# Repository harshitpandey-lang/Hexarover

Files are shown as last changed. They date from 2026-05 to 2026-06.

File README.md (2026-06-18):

---
[hexarover zine.pdf](https://github.com/user-attachments/files/28886290/hexarover.zine.pdf)

# HexaRover

> This is an intelligent six wheeled rover inspired from the mars exploration rover and it will be same in design and will be lego based and the main feature of the design is going to be the ease of recreatibility of the complete project. The electronics are replacable while the cadd designes of the legos will be available here with dimesions and links. The desines of the legos can also be used to creat any other project in future also.

---

## Overview

HexaRover is a modular robotics platform built to explore and operate in environments that are difficult, hazardous, or inaccessible to humans. The project integrates embedded electronics, computer vision, wireless communication, and mechanical design into a single scalable rover architecture.

Designed with reliability and adaptability in mind, HexaRover serves as a foundation for experimentation in autonomous systems, remote operations, and intelligent robotics. This is a kind of gateway to enter into lego based bot creation by anybody and embedded systems.

---
## Inspiration 

I was truly amazed and inpsired from the mars rover made by nasa for the mars exploration and its replica by nasa-jpl which github is given here https://github.com/nasa-jpl/open-source-rover. The rovers were very beutiful yet cool and the things which got me in was the structure of them can be made through smaller parts. 
### Probelem being solved
the probelm in these rovers are that they cant be created with the materials which are present in our room solely we need to buy a lot of minutes and minute hardware products and mechanical parts.
So, I decided to make something that can be cretaed using jsut a 3d printer and pvc pipes.

some images of the nasa-jpl rover is given here 




## Mission

To develop a six wheel functional rover which is very cool both in desines and in working. The electronics can be replaced by anybody while the main designes and mechanical parts can be 3d printed by anyone. The recretion of the rover is very easy and the 3d parts can also be used to creat other project in future as well.

---

## Key Features

* Six-Wheel Drive Mobility System
* Modular Electronics Architecture
* ESP32-Based Embedded Control
* Raspberry Pi Vision Processing
* Live Camera Streaming
* Wireless Communication
* Expandable Sensor Support
* Terrain-Oriented Chassis Design
* Remote Monitoring and Operation
* Future Autonomous Navigation Capability

---

## Project Structure

```text
HexaRover/
│
├── README.md
├── LICENSE
├── .gitignore
├── AUTHOR.md
│
├── docs/
├── hardware/
├── software/
└── media/
```

---

## Future Goals

* Autonomous Navigation
* Terrain Mapping
* Object Detection
* Sensor Fusion
* AI-Assisted Decision Making
* Multi-Rover Collaboration

## The Design

The Wirring diagram is given here in kicadd and the kicadd file is also attached in this repo, since the design doesnt require any kind of pb so no pcb was designed for this project while the wirring of the componenets is gievn here 
{85047B80-3A90-4A06-985E-AE78F9C303FE}
Untitled - June 03, 2026 at 04 48 04

---

## Contributing

Contributions are welcome.

If you would like to improve the project:

1. Fork the repository.
2. Create a feature branch.
3. Make your changes.
4. Test thoroughly.
5. Submit a pull request with a clear description of the changes.

Please ensure that all contributions align with the project's objectives and maintain code quality standards.

---

### Access The Parts From Here-

CAD
Wirrings
BOM
Jornel
Steps To Recreate

## License

This project is licensed under the MIT License.

See the LICENSE file for complete details.

---

<div align="center">

### HexaRover

*Exploring the Unknown.*

</div>

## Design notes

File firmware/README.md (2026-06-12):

# Firmware Structure

This directory contains the complete ESP32 firmware for HexaRover.

## Build & Upload

Using PlatformIO:
```bash
cd firmware
pio run -e esp32doit-devkit-v1
pio run -e esp32doit-devkit-v1 --target upload
```

Or Arduino IDE:
- Open `src/main.cpp`
- Select board: ESP32 DevKit V1
- Select port and upload

## File Organization

```
firmware/
├── platformio.ini          # Build configuration
├── src/
│   ├── main.cpp            # Main firmware entry point
│   ├── motor_controller.h/cpp   # BTS7960 motor driver interface
│   ├── servo_controller.h/cpp   # MG946R servo interface  
│   ├── sensor_manager.h/cpp     # IMU, GPS, ultrasonic handling
│   ├── receiver.h/cpp          # FlySky FS-iA6B iBUS receiver
│   ├── telemetry.h/cpp         # Telemetry to Raspberry Pi
│   └── main.py             # Raspberry Pi control app
├── setup.py                # RPi dependency installer
└── WIRING.md              # Hardware connection guide
```

## Module Overview

### Motor Controller
Manages dual BTS7960 motor drivers with PWM speed control. Supports independent left/right control and synchronized forward/reverse motion.

### Servo Controller  
Controls four MG946R steering servos via PWM. All servos synchronized for unified steering angle.

### Sensor Manager
Aggregates data from:
- MPU6050 IMU (roll, pitch, yaw via I2C)
- NEO-6M GPS (coordinates, satellite count via UART1)
- HC-SR04 ultrasonic sensors (front & rear distance via GPIO)

### Receiver Manager
Decodes FlySky FS-iA6B iBUS protocol at 115200 baud. Extracts 14 channels with failsafe detection on signal loss.

### Telemetry Manager
Sends formatted telemetry packets to Raspberry Pi at 10 Hz containing mode, distances, GPS, and orientation data.

## Key Features

- **Modular Class Architecture**: Each subsystem is independent and reusable
- **Failsafe Logic**: Automatic stop & center steering on receiver signal loss
- **Autonomous Mode**: Obstacle avoidance with front distance sensor
- **Live Telemetry**: Continuous sensor streaming to Raspberry Pi
- **Debug Output**: Serial console logging for development

## Compilation Requirements

- PlatformIO IDE or Arduino IDE
- ESP32 Board Support Package
- Libraries:
  - ESP32Servo
  - MPU6050
  - TinyGPS++
  - Adafruit-BusIO

All handled automatically by platformio.ini

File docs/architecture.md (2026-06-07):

# HexaRover Architecture

## Overview

HexaRover is a modular ESP32-powered robotic rover platform designed for education, experimentation, and open-source robotics development. The system combines custom 3D-printed structural components, wireless communication, embedded control systems, and modular hardware interfaces to create a platform that can be easily assembled, modified, and extended.

The architecture emphasizes:

* Modularity
* Reproducibility
* Scalability
* Low-cost manufacturing
* Open-source development
* Educational accessibility

---

# System Architecture

```text
                    ┌─────────────────────┐
                    │   User Controller   │
                    │ (Phone / Web App)   │
                    └──────────┬──────────┘
                               │
                        Wi-Fi / Bluetooth
                               │
                               ▼
                    ┌─────────────────────┐
                    │       ESP32         │
                    │ Main Control Unit   │
                    └───────┬─────┬───────┘
                            │     │
            ┌───────────────┘     └───────────────┐
            ▼                                     ▼

   ┌─────────────────┐                  ┌─────────────────┐
   │ Motor Driver    │                  │ Sensor Network  │
   │ (L298N/TB6612)  │                  │ Expansion Bus   │
   └────────┬────────┘                  └────────┬────────┘
            │                                    │
            ▼                                    ▼

   ┌─────────────────┐                ┌──────────────────┐
   │ Drive Motors    │                │ Future Sensors   │
   │ Wheel System    │                │ IMU, Ultrasonic  │
   └─────────────────┘                │ GPS, Camera etc. │
                                      └──────────────────┘
```

---

# Hardware Architecture

## Chassis Layer

The chassis serves as the structural foundation of HexaRover.

### Responsibilities

* Support electronic components
* Mount motors and wheels
* Protect internal systems
* Enable modular expansion

### Construction

The chassis consists of:

* Sunboard prototype structure
* Custom 3D-printed components
* LEGO-inspired modular connectors
* Reinforcement supports
* Electronics mounting points

### Design Principles

* Lightweight construction
* Easy assembly
* Replaceable components
* Standardized connection interfaces

---

## Mechanical Subsystem

The mechanical subsystem converts electrical energy into rover movement.

### Components

| Component | Function |
| --- | --- |
| Drive Wheels | Ground mobility |
| Motor Mounts | Secure motor positioning |
| Connector System | Structural assembly |
| Reinforcement Elements | Load distribution |
| Chassis Frame | System support |

### Features

* Modular wheel assemblies
* Serviceable components
* Expandable frame design
* Future payload support

---

## Electronics Architecture

The electronics subsystem acts as the control and communication backbone of the rover.

### Core Controller

**ESP32 Development Board**

Responsibilities:

* Wireless communication
* Sensor data processing
* Motor control
* Firmware execution
* Future AI integrations

### Why ESP32

* Dual-core processor
* Wi-Fi support
* Bluetooth support
* Multiple GPIO interfaces
* Large community support
* Cost effectiveness

---

## Power Distribution Layer

The power system distributes energy to all rover subsystems.

### Responsibilities

* Stable voltage delivery
* Current protection
* Battery integration
* Component isolation

### Planned Power Flow

```text
Battery Pack
      │
      ▼
Power Regulation
      │
 ┌────┴────┐
 ▼         ▼

ESP32   Motor Driver
            │
            ▼
         Motors
```

### Future Improvements

* Battery monitoring
* Overcurrent protection
* Charging subsystem
* Power telemetry

---

## Motor Control Architecture

The motor control subsystem interfaces between the ESP32 and drive motors.

### Responsibilities

* Speed control
* Direction control
* Differential steering
* PWM signal processing

### Planned Hardware

* L298N Motor Driver (Prototype)
  or
* TB6612FNG (Future Upgrade)

### Control Flow

```text
User Command
      │
      ▼
ESP32 Firmware
      │
      ▼
Motor Driver
      │
      ▼
DC Motors
```

---

# Sensor Architecture

HexaRover is designed with a sensor-first expansion philosophy.

The base platform functions without sensors but includes provisions for future integration.

### Planned Sensor Modules

| Sensor | Purpose |
| --- | --- |
| Ultrasonic | Obstacle detection |
| IMU | Orientation tracking |
| GPS | Navigation |
| Camera | Vision processing |
| Encoders | Motion feedback |
| Environmental Sensors | Data collection |

### Expansion Goals

* Plug-and-play sensor integration
* Standardized interfaces
* Modular firmware support

---

# Communication Architecture

The communication subsystem enables wireless control and monitoring.

## Bluetooth Mode

Designed for:

* Mobile control
* Quick setup
* Offline operation

### Use Cases

* Manual driving
* Classroom demonstrations
* Testing

---

## Wi-Fi Mode

Designed for:

* Long-range operation
* Web dashboard control
* Remote monitoring

### Future Features

* OTA firmware updates
* Telemetry streaming
* Multi-device control

---

# Software Architecture

The software stack follows a layered design.

```text
Application Layer
        │
        ▼
Control Layer
        │
        ▼
Hardware Abstraction Layer
        │
        ▼
ESP32 Hardware
```

---

## Application Layer

Responsible for:

* User commands
* Dashboard interfaces
* Autonomous routines
* Data visualization

---

## Control Layer

Responsible for:

* Motion algorithms
* Steering logic
* Sensor fusion
* Decision making

---

## Hardware Abstraction Layer

Provides a consistent interface between software and hardware.

### Benefits

* Easier maintenance
* Hardware independence
* Improved scalability
* Cleaner code organization

---

# Firmware Architecture

The firmware is divided into independent modules.

```text
Firmware
│
├── Motor Controller
├── Wireless Manager
├── Sensor Manager
├── Power Monitor
├── Configuration Manager
└── Diagnostics Module
```

Each module performs a specific task and communicates through well-defined interfaces.

---

# Repository Architecture

```text
HexaRover/
│
├── CAD/
│   ├── Connectors/
│   ├── Chassis/
│   └── Assembly/
│
├── Hardware/
│   ├── Components/
│   ├── Wiring/
│   └── PCB/
│
├── Firmware/
│   ├── Core/
│   ├── Drivers/
│   ├── Sensors/
│   └── Communication/
│
├── Docs/
│   ├── Architecture.md
│   ├── Journal.md
│   ├── Assembly.md
│   └── Wiring.md
│
├── Images/
│
└── README.md
```

---

# Scalability Roadmap

The architecture has been designed to support future enhancements without requiring a complete redesign.

### Planned Upgrades

* Autonomous navigation
* Computer vision
* AI-assisted driving
* ROS integration
* Custom PCB development
* Swarm robotics experimentation
* Edge AI processing

---

# Design Philosophy

HexaRover is built around five core principles:

### Modularity

Every subsystem should be replaceable without affecting the rest of the platform.

### Accessibility

The rover should be buildable using commonly available tools and components.

### Open Source

All designs, firmware, and documentation should remain openly available.

### Educational Value

The platform should serve as a practical learning tool for robotics and embedded systems.

### Scalability

The architecture should support growth from a simple rover to a sophisticated autonomous robotics platform.

---

# Conclusion

HexaRover is more than a rover project; it is a modular robotics platform designed to bridge mechanical engineering, electronics, embedded systems, and software development. The architecture prioritizes flexibility, maintainability, and reproducibility, ensuring that future contributors can extend the platform while preserving a clean and organized system design.

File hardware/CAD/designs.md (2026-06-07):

WhatsApp Image 2026-06-07 at 10 52 28 AM
the cadd designes are given here one by one WhatsApp Image 2026-06-07 at 10 46 33 AM
WhatsApp Image 2026-06-07 at 10 46 33 AM (1)
WhatsApp Image 2026-06-07 at 10 46 34 AM
WhatsApp Image 2026-06-07 at 10 46 34 AM (1)
WhatsApp Image 2026-06-07 at 10 46 35 AM
WhatsApp Image 2026-06-07 at 10 46 38 AM
WhatsApp Image 2026-06-07 at 10 46 36 AM
WhatsApp Image 2026-06-07 at 10 46 37 AM
WhatsApp Image 2026-06-07 at 10 46 37 AM (1)

WhatsApp Image 2026-06-07 at 10 52 30 AM
WhatsApp Image 2026-06-07 at 10 52 29 AM (1)
WhatsApp Image 2026-06-07 at 10 52 29 AM

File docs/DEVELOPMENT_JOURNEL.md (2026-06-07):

# HexaRover Development Journal

## Project Overview

HexaRover is an open-source modular rover platform designed to be accessible, reproducible, and educational. The project combines custom 3D-printed structural components, ESP32-based control electronics, and a lightweight chassis architecture to create a robotics platform that can be assembled and modified by students, hobbyists, and makers.

The primary objective of the project is to develop a rover that can be reproduced using commonly available materials while providing opportunities to learn CAD design, mechanical engineering, embedded systems, electronics integration, and open-source hardware development.

---

## Concept Development and Chassis Design

The project began with an evaluation of available components and manufacturing constraints. Rather than designing a conventional rover around expensive custom-machined parts, the design philosophy focused on modularity and ease of fabrication.

A lightweight chassis structure was selected as the foundation of the platform. Initial prototypes were constructed using sunboard panels to rapidly validate dimensions, structural layout, and component placement before committing to detailed CAD development.

This prototyping phase established the overall footprint of the rover and provided a practical framework for future mechanical design decisions.

### Key Deliverables

* Initial rover architecture defined.
* Chassis dimensions finalized.
* Structural layout validated through physical prototyping.
* Manufacturing constraints identified before CAD development.

---

## Development of Modular Mechanical Components

A major goal of HexaRover is to enable easy assembly and customization. To achieve this, a modular mechanical ecosystem was developed using LEGO-inspired design principles.

Using Autodesk Fusion, a collection of interlocking structural components was designed to serve as the foundation of the rover's mechanical framework. These parts were dimensioned for 3D printing and intended to allow users to modify or expand the rover without redesigning the entire platform.

The design process focused on creating standardized connection interfaces that could be reused throughout the system.

### Components Developed

* Structural connectors
* Joint mechanisms
* Mounting interfaces
* Support brackets
* Modular attachment elements

### Engineering Considerations

* Printability on consumer-grade 3D printers.
* Dimensional consistency across all modules.
* Structural integrity under expected operating loads.
* Ease of assembly and replacement.

---

## Mechanical System Integration

Following the development of individual components, the project entered the assembly design stage.

The modular parts were integrated into a complete rover architecture within Fusion. Multiple iterations were performed to ensure alignment between structural members, mounting locations, and future electronics integration requirements.

This stage transformed a collection of individual components into a cohesive mechanical system capable of supporting mobility hardware, electronics, and future payloads.

### Accomplishments

* Complete digital assembly created.
* Structural relationships validated.
* Mounting geometry established.
* Mechanical compatibility verified across modules.

### Challenges

As with most modular systems, dimensional tolerances became increasingly important as the number of interconnected parts increased. Several design revisions were performed to improve compatibility and simplify future assembly.

---

## Structural Optimization

To improve durability and load distribution, additional reinforcement elements were introduced into the design.

These components were intended to increase chassis rigidity while maintaining the modular philosophy of the project. Support structures were added to improve the strength of critical mounting locations and reduce stress concentrations throughout the frame.

This phase marked the transition from a proof-of-concept model toward a more robust engineering design.

### Outcomes

* Increased structural stability.
* Improved load distribution.
* Enhanced support for future electronics integration.
* Better long-term durability of the chassis.

---

## Repository Architecture and Documentation

In parallel with hardware development, work began on organizing the project's software and documentation infrastructure.

The repository was structured to support future development, collaboration, and reproducibility. Documentation was treated as a core component of the project rather than an afterthought.

The goal is to ensure that anyone can reproduce the rover using only the repository contents and commonly available tools.

---

## Visualization and Design Validation

Before physical fabrication, high-quality rendered models were generated from the completed CAD assembly.

These renders served multiple purposes:

* Visual verification of the final design.
* Documentation and presentation material.
* Identification of potential design inconsistencies.
* Creation of media assets for project communication.

The rendering process provided an opportunity to review the complete system before moving further into fabrication and electronics integration.

---

## Electronics Planning and System Architecture

With the mechanical design substantially complete, attention shifted toward electronics integration.

The control architecture is centered around the ESP32 platform due to its processing capabilities, wireless connectivity, and suitability for robotics applications.

Before creating formal schematics, the complete wiring architecture was first developed on paper. This approach allowed signal routing, power distribution, and component relationships to be analyzed before implementation in electronic design software.

### Areas of Focus

* ESP32 pin allocation.
* Motor control architecture.
* Power distribution planning.
* Sensor integration pathways.
* Future expansion capabilities.

### Design Philosophy

The electronics system is being developed with the same modular principles as the mechanical structure, allowing future upgrades without requiring significant redesign of the platform.

---

## Current Status

At the present stage of development:

* Mechanical architecture has been designed and validated digitally.
* Modular 3D-printable components have been developed.
* Structural reinforcement elements have been incorporated.
* Repository organization and documentation have been established.
* Visual renders have been generated.
* Electronics planning and wiring architecture are underway.

The project is now transitioning from digital design and planning into fabrication, electronics implementation, firmware development, and system testing.

---

## Future Work

Upcoming development milestones include:

* Fabrication of 3D-printed components.
* Assembly of the physical rover platform.
* Electronics integration.
* PCB and schematic development.
* ESP32 firmware implementation.
* Wireless control functionality.
* Sensor integration and testing.
* Field validation and performance optimization.
* Release of complete open-source documentation.

---

## Conclusion

HexaRover represents an effort to create an accessible and reproducible robotics platform that bridges mechanical design, electronics, embedded systems, and open-source engineering. By emphasizing modularity, documentation, and ease of replication, the project aims to provide a practical learning platform for students, makers, and robotics enthusiasts while serving as a foundation for future experimentation and development.

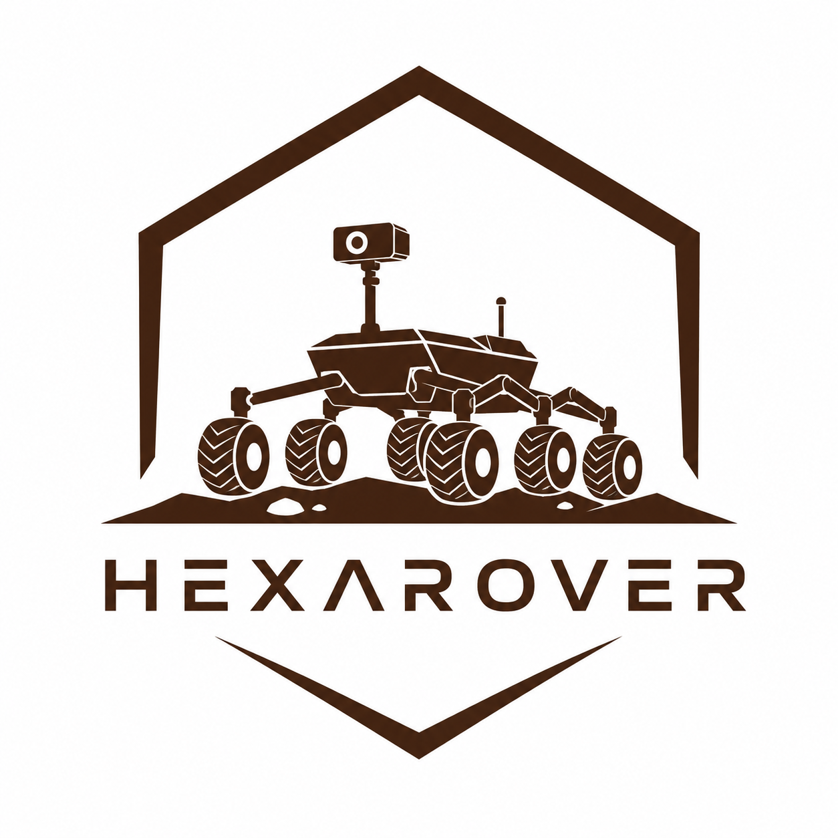
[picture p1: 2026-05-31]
Media/rover_images/ May 30, 2026, 09_19_28 PM.png

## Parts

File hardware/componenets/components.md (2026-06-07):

71ojeUPQI9L
51cDDThzC1L
41vruQ(3)
NEO6MV2-gps-module_9fbf4879-e287-42eb-b1ce-58d4beed52e1
unnamed_64e02225-e6c5-4890-8380-92216c35b1bb

Ultrasonic-Sensor-Module-HC-SR04
MPU6050-Gyroscope-Sensor
LM25962ABuckStep-downPowerConverterModuleDC4-40Vto1 3-37VwithLEDVoltmeter2
GB37-55512VDCGearMotor-300RPM_3_large
GB37-55512VDCGearMotor-300RPM_2_large

DoubleBTS796043AH-BridgeHigh-PowerStepperMotorDriverModule_2
DoubleBTS796043AH-BridgeHigh-PowerStepperMotorDriverModule_1
BTS7960-43a-dual-motor-controller-7-Cropped_480x480
BlueskyMini5V3AUBECforFPVGimbalandRCDroneModels2
616zO4AQmmL _SL1500_
61l1xE23BhL _SL1500_
61b2MmjYhOL _SL1000_

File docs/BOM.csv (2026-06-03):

Category | Supplier | Component | Quantity | Unit Price INR | Subtotal INR | Purchase Link
Drive System | Quartz Components | GB37-555 12V DC Gear Motor 300RPM | 6 | 608 | 3648 | https://quartzcomponents.com/products/gb37-555-12v-dc-gear-motor-300rpm?variant=45639417790698
Drive System | Quartz Components | Double BTS7960 43A H-Bridge Driver | 2 | 273 | 546 | https://quartzcomponents.com/products/double-bts7960-43a-h-bridge-high-power-stepper-motor-driver-module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
Steering System | Robu.in | TowerPro MG946R Digital Metal Gear Servo | 4 | 438 | 1752 | https://robu.in/product/towerpro-mg946r-digital-high-torque-metal-gear-servo-motor/
Wheel System | Sun Electronics | 11cm x 4cm High Load Robotic Wheel | 6 | 140 | 840 | https://sunelectronics.co.in/product/robotic-wheel-for-high-load-11cm-x-4cm-wheel-for-robotfor-engineering-project/
Power System | Quartz Components | WATTNINE 12V 7.2Ah Li-Ion Battery Pack | 1 | 1652 | 1652 | https://quartzcomponents.com/products/12v-7200mah-li-ion-battery-pack-with-1-year-warranty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
Power System | Quartz Components | LM2596 Buck Converter with Voltmeter | 1 | 108 | 108 | https://quartzcomponents.com/products/lm2596-2a-buck-step-down-power-converter-module-dc-4-40v-to-1-3-37v-with-led-voltmeter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
Power System | Quartz Components | XT60 Connector Pair | 2 | 26 | 52 | https://quartzcomponents.com/products/xt60?variant=42158646624490
Navigation | Quartz Components | NEO6MV2 GPS Module | 1 | 235 | 235 | https://quartzcomponents.com/products/neo6mv2-gps-module-with-flight-controller?variant=31898002980999
Sensors | Quartz Components | MPU6050 Gyroscope Accelerometer Module | 1 | 156 | 156 | https://quartzcomponents.com/products/mpu6050-gyroscope-accelerometer-sensor?variant=31897777733767
Sensors | Quartz Components | HC-SR04 Ultrasonic Sensor | 4 | 72 | 288 | https://quartzcomponents.com/products/hc-sr04-ultrasonic-sensor-module?variant=31897769410695
Vision System | Sun Electronics | Raspberry Pi 3 Camera 5MP | 1 | 260 | 260 | https://sunelectronics.co.in/product/raspberry-pi-3-camera-5-mp/
Wiring | Quartz Components | Jumper Wire Combo Pack (120pcs) | 1 | 145 | 145 | https://quartzcomponents.com/products/jumper-wires-combo-pack-male-to-male-male-to-female-female-to-female-set-of-120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
Wiring | Robu.in | Servo Extension Cable 15cm | 4 | 50 | 200 | https://robu.in/product/safeconnect-twisted-15cm-22awg-servo-lead-extension-jr-cable-with-self-locking-hook/
Wiring | Robu.in | PVC Heat Shrink Sleeve 93mm | 1 | 31 | 31 | https://robu.in/product/pvc-heat-shrink-sleeve-93mm-orange/
Control System | User Inventory | Raspberry Pi 4 Model B | 1 | 0 | 0 | Already Owned
Control System | User Inventory | FlySky FS-i6 Transmitter | 1 | 0 | 0 | Already Owned
Control System | User Inventory | FlySky Receiver | 1 | 0 | 0 | Already Owned
Control System | User Inventory | 32GB Class 10 MicroSD Card | 1 | 0 | 0 | Already Owned
Power System | Amazon | 15A ATC Automotive Blade Fuse | 1 | 80 | 80 | https://amzn.in/d/08DSf7vK
Power System | Amazon | DC Power Jack Connector Set (10 Male + 10 Female) | 1 | 299 | 299 | https://amzn.in/d/0b6YXhBp
Power System | Amazon | RC Servo BEC UBEC Voltage Regulator 5V 15A | 1 | 1672 | 1672 | https://amzn.in/d/0f6fojOy
Control System | Quartz Components | ESP32 30 Pin CP2102 Development Board | 1 | 385 | 385 | https://quartzcomponents.com/products/esp32-30-pin-development-board-with-wi-fi-and-bluetooth
TOTAL |  |  |  |  | 12547

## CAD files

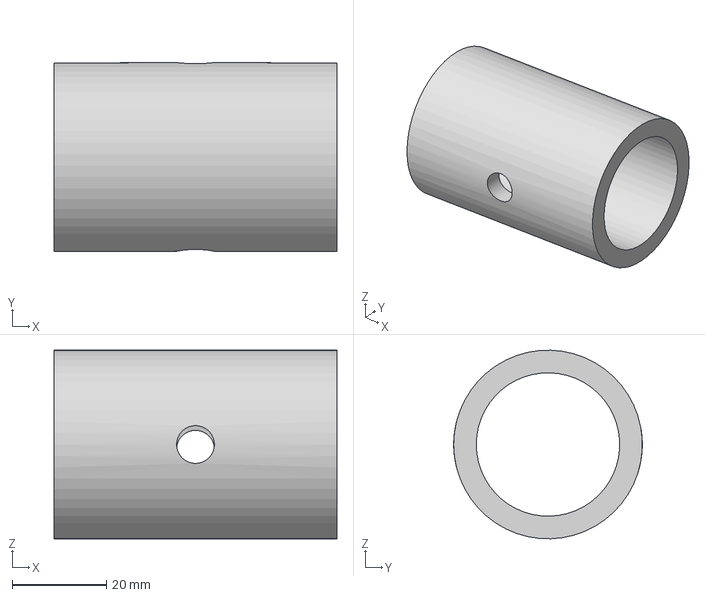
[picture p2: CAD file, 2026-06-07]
hardware/CAD/J8.step
60.0 x 40.0 x 40.0 mm

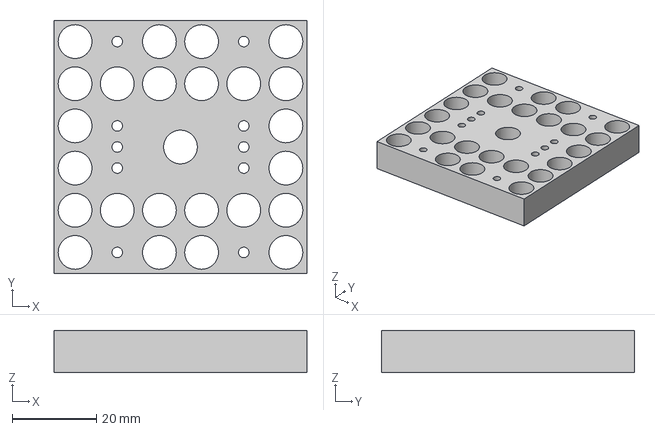
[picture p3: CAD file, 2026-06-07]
hardware/CAD/J3.step
60.0 x 60.0 x 10.0 mm

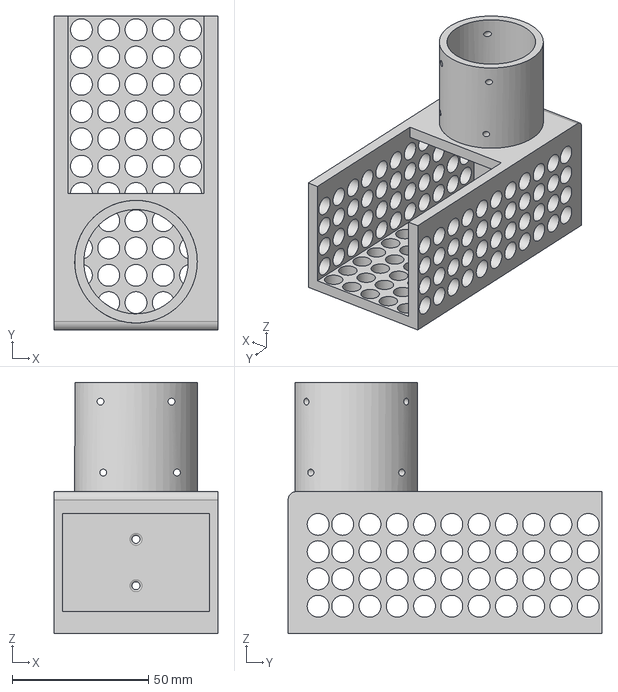
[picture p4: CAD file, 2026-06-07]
hardware/CAD/j12.step
60.0 x 115.0 x 92.0 mm

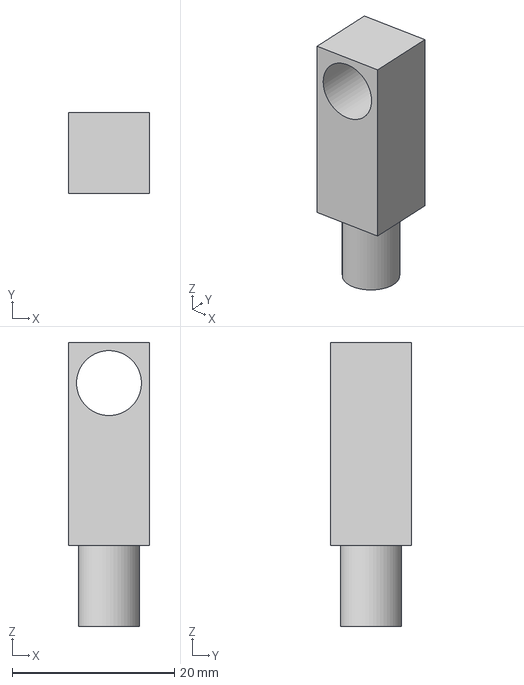
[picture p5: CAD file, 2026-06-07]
hardware/CAD/J4.step
10.0 x 10.0 x 35.0 mm

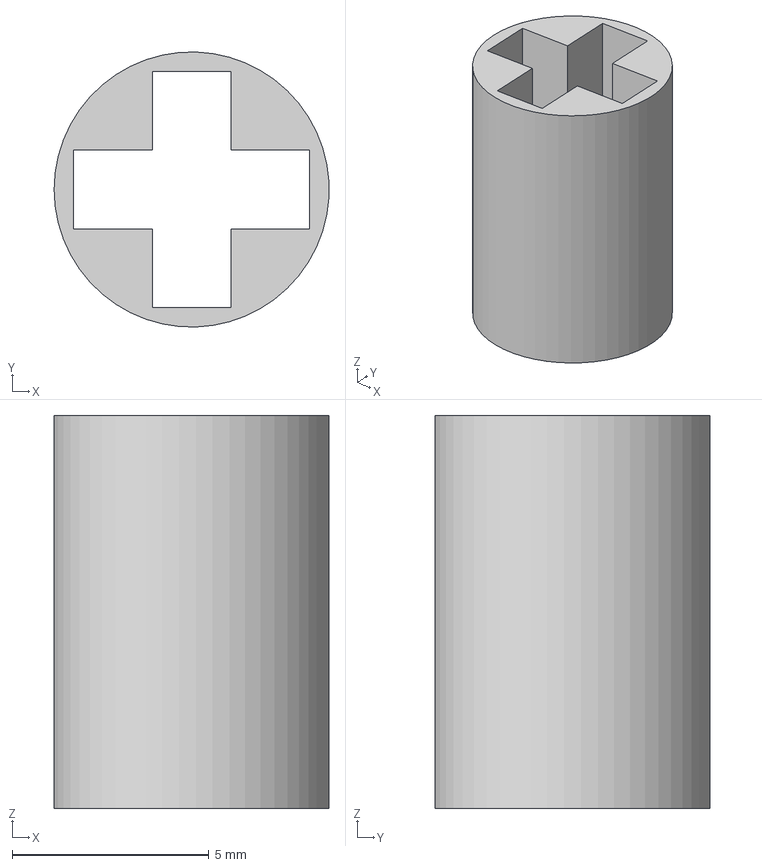
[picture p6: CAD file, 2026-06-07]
hardware/CAD/J2.step
6.99 x 7.00 x 10.0 mm

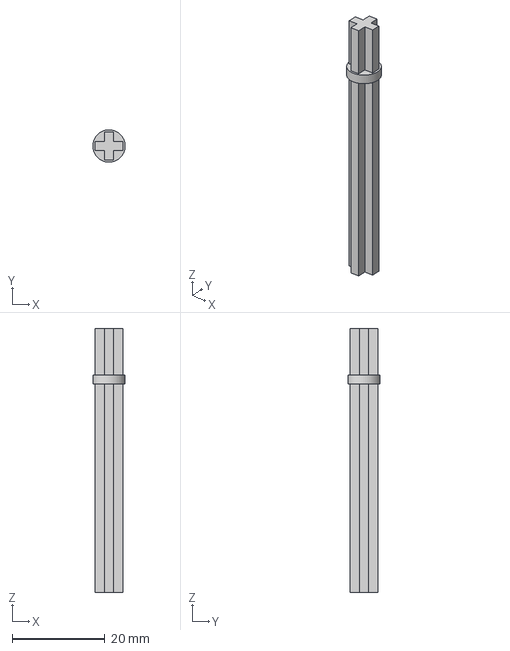
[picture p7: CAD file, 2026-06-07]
hardware/CAD/J1.step
6.99 x 7.00 x 57.0 mm

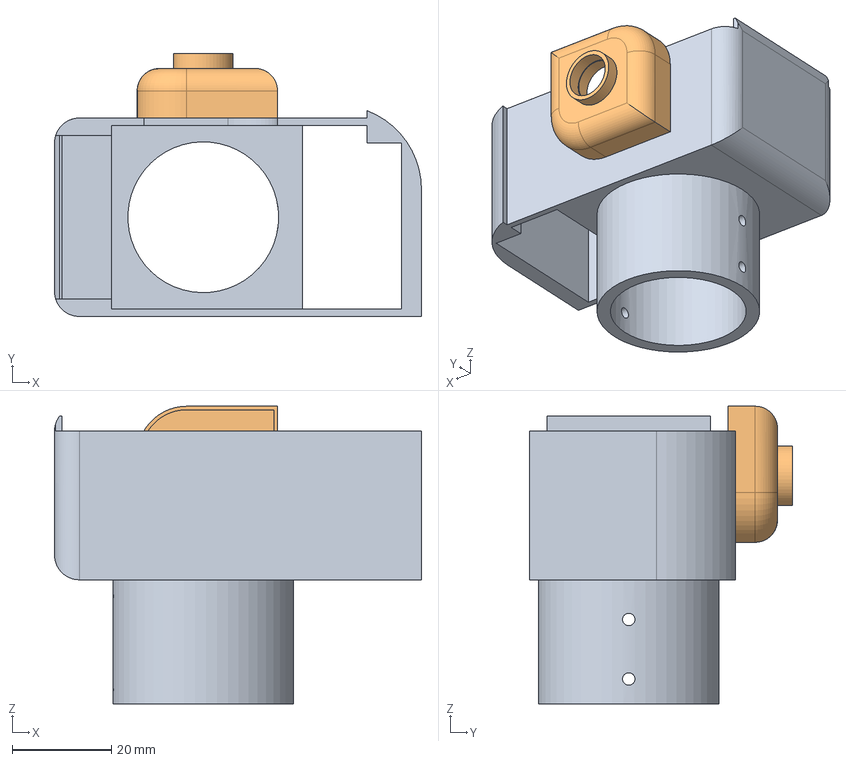
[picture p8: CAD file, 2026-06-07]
hardware/CAD/J13.step
74.0 x 53.0 x 60.0 mm

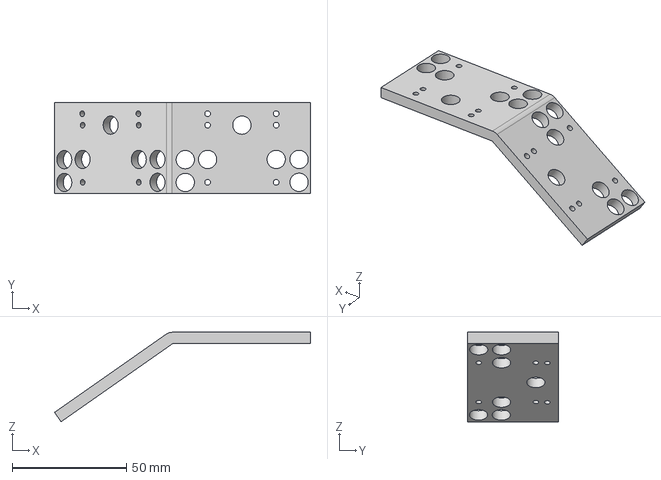
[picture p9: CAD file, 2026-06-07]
hardware/CAD/J6.step
112.0 x 40.0 x 39.1 mm

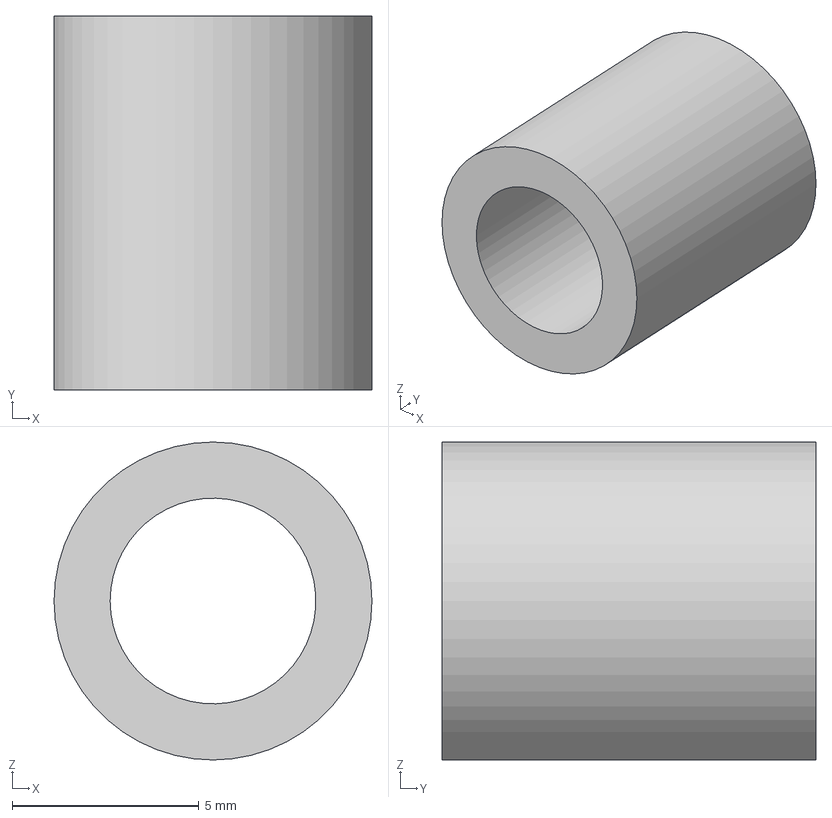
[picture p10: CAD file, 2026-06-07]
hardware/CAD/L3.step
8.50 x 10.0 x 8.50 mm

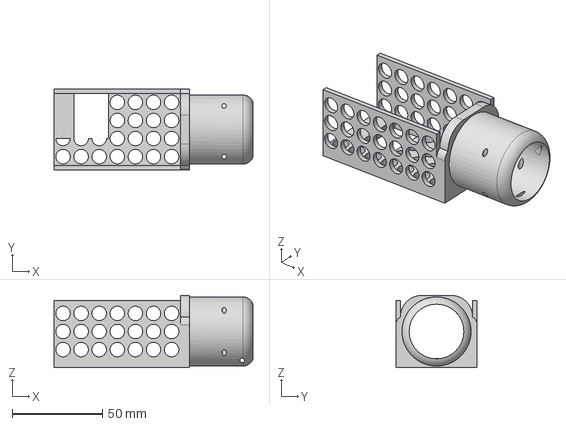
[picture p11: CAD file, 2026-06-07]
hardware/CAD/j11.step
110.0 x 45.0 x 40.0 mm

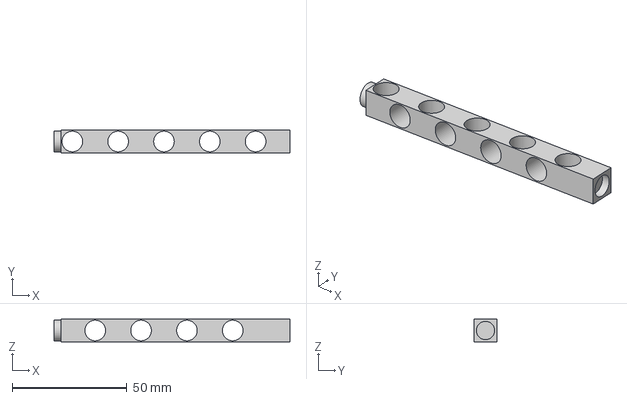
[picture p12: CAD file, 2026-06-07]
hardware/CAD/L2.step
103.0 x 10.0 x 10.0 mm

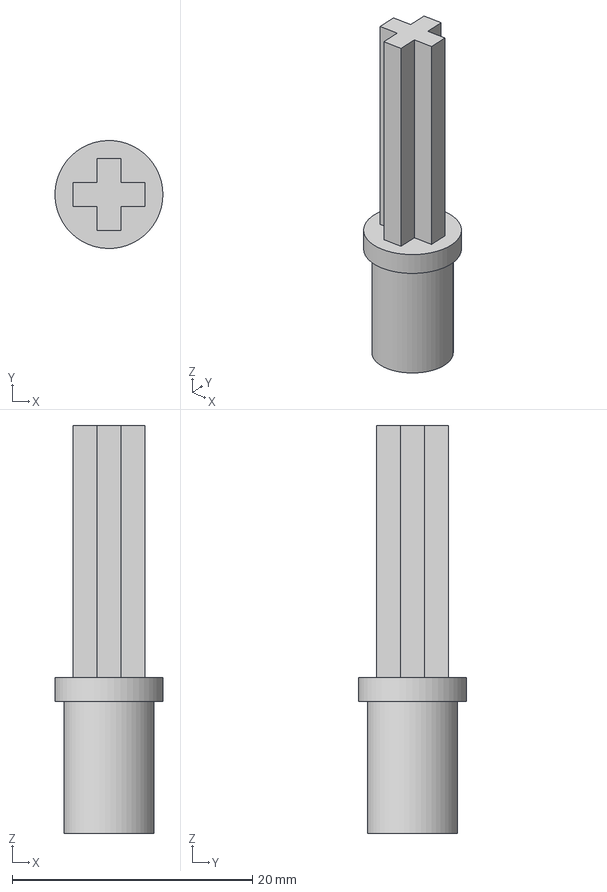
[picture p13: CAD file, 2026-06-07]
hardware/CAD/J5.step
8.99 x 9.00 x 34.0 mm

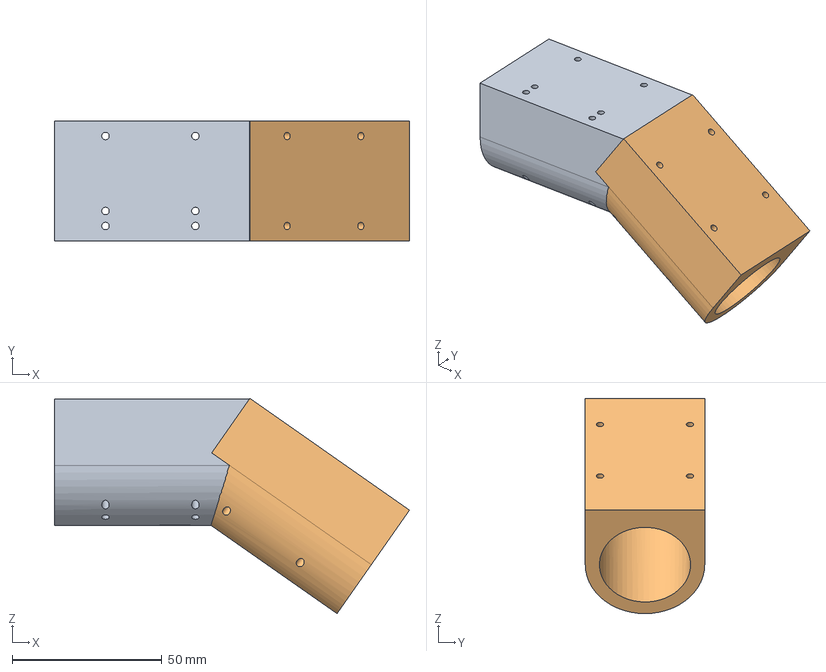
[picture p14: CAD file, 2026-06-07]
hardware/CAD/J7.step
118.4 x 40.0 x 71.8 mm

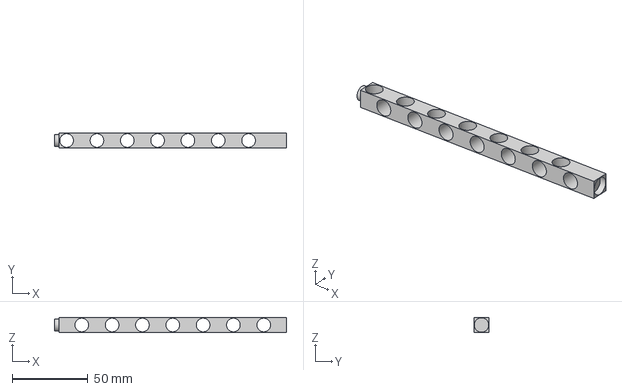
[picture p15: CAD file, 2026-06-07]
hardware/CAD/L1.step
153.0 x 10.0 x 10.0 mm

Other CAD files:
hardware/CAD/L4.step
hardware/CAD/Full rover.f3d
hardware/CAD/J1.f3d
hardware/CAD/J13.f3d
hardware/CAD/J2.f3d
hardware/CAD/J3.f3d
hardware/CAD/J4.f3d
hardware/CAD/J5.f3d
hardware/CAD/J6.f3d
hardware/CAD/J7.f3d
hardware/CAD/J8.f3d
hardware/CAD/L1.f3d
hardware/CAD/L2.f3d
hardware/CAD/L3.f3d
hardware/CAD/j11.f3d
hardware/CAD/j12.f3d

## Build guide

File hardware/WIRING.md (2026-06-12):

# HexaRover Hardware Wiring Guide

This document describes all electrical connections for the HexaRover platform.

## System Overview

The rover uses a distributed control architecture with three main computational nodes:
- **ESP32**: Main control unit managing motors, servos, and sensors
- **Raspberry Pi 4**: Secondary processor for vision and advanced autonomy
- **FlySky FS-iA6B**: Remote control receiver for manual operation

Power is distributed from a central battery through two main motor drivers and several regulators for different voltage requirements.

## Power Architecture

```
12V LiPo Battery
    │
    ├─ 20A Fuse
    ├─ Main Switch
    │
    ├─→ BTS7960 #1 Motor Driver (12V direct)
    ├─→ BTS7960 #2 Motor Driver (12V direct)
    │
    ├─→ UBEC 5V 15A Regulator (servo power)
    │
    └─→ LM2596 Buck Converter → 5V (ESP32 power)
```

### Battery Specifications
- Type: LiPo 2S-4S configuration (7.4V to 14.8V nominal)
- Recommended capacity: 10000 mAh or higher for extended runtime
- Discharge rate: 50C minimum for sustained motor operation
- Operating temperature: 0-40°C

### Voltage Regulators
- **UBEC (Universal Battery Elimination Circuit)**: Supplies 5V at 15A to servo motors
- **LM2596**: Adjustable step-down converter set to 5V for ESP32 VIN pin

## Motor Control System

The rover uses two independent BTS7960 motor drivers to control left and right motor sets independently, allowing for differential steering and redundancy.

### BTS7960 Motor Driver #1 (Left Side - 3 Motors in Parallel)

**Power Connections:**
```
B+  ──→ +12V from battery
B-  ──→ GND (battery negative)
M+  ──→ Left motor group positive
M-  ──→ Left motor group negative
```

**Control Signals (to ESP32):**
```
RPWM (Forward PWM)  ──→ GPIO 25
LPWM (Reverse PWM)  ──→ GPIO 26
R_EN (Right Enable) ──→ GPIO 33 (tied HIGH)
L_EN (Left Enable)  ──→ GPIO 32 (tied HIGH)
```

### BTS7960 Motor Driver #2 (Right Side - 3 Motors in Parallel)

**Power Connections:**
```
B+  ──→ +12V from battery
B-  ──→ GND (battery negative)
M+  ──→ Right motor group positive
M-  ──→ Right motor group negative
```

**Control Signals (to ESP32):**
```
RPWM (Forward PWM)  ──→ GPIO 27
LPWM (Reverse PWM)  ──→ GPIO 14
R_EN (Right Enable) ──→ GPIO 13 (tied HIGH)
L_EN (Left Enable)  ──→ GPIO 12 (tied HIGH)
```

### Speed Control Logic

PWM Frequency: 5 kHz
PWM Resolution: 8-bit (0-255 values)

**Motor direction commands:**
- Stop: RPWM = 0, LPWM = 0
- Forward: RPWM = speed value, LPWM = 0
- Reverse: RPWM = 0, LPWM = speed value
- Left turn: Left motor reduced, right motor full
- Right turn: Right motor reduced, left motor full

## Servo Steering System

Four MG946R digital servos provide steering control at all four corners for omnidirectional mobility.

**Servo GPIO Assignments:**
| Servo Position | GPIO | Function |
|---|---|---|
| Front Left | 4 | Steering angle |
| Front Right | 5 | Steering angle |
| Rear Left | 18 | Steering angle |
| Rear Right | 19 | Steering angle |

**Power Distribution:**
- All servo power: 5V from UBEC regulator
- All servo GND: Common ground with main power system
- PWM signals: 3.3V logic from ESP32

**Servo Operating Range:**
- Pulse width: 1000-2000 microseconds
- Angle mapping: 45° (full left) → 1000 μs, 90° (center) → 1500 μs, 135° (full right) → 2000 μs
- Frequency: 50 Hz
- All servos synchronized for coordinated steering

## Sensor Connections

### MPU6050 Inertial Measurement Unit (I2C Bus)

Provides 3-axis acceleration and rotation rate measurements for orientation determination.

```
VCC ──→ 3.3V from ESP32
GND ──→ Common GND
SDA ──→ GPIO 21 (ESP32 I2C SDA)
SCL ──→ GPIO 22 (ESP32 I2C SCL)
AD0 ──→ GND (sets I2C address to 0x68)
INT ──→ Optional, not used
```

**Data Output:**
- Roll angle (degrees)
- Pitch angle (degrees)
- Yaw rate (degrees/second)
- Acceleration vectors (X, Y, Z axes)

### NEO-6M GPS Module (UART)

Provides global positioning data and satellite lock information via NMEA protocol.

```
VCC ──→ 5V regulated power
GND ──→ Common GND
RX  ──→ GPIO 17 (ESP32 TX on Serial1)
TX  ──→ GPIO 16 (ESP32 RX on Serial1)
```

**UART Configuration:**
- Baud rate: 9600
- Data bits: 8
- Stop bits: 1
- Parity: None

**Data Output:** NMEA sentences parsed for:
- Latitude/Longitude (6 decimal places)
- Satellite count
- Position fix status

### HC-SR04 Ultrasonic Distance Sensor - Front

Measures distance to obstacles in front of rover.

```
VCC  ──→ 5V regulated power
GND  ──→ Common GND
TRIG ──→ GPIO 2 (3.3V logic)
ECHO ──→ GPIO 34 (with voltage divider: 1kΩ series + 2kΩ to GND)
```

**Voltage Divider for Echo:**
- Reduces 5V sensor output to 3.3V safe for ESP32
- 1kΩ resistor in series from sensor
- 2kΩ resistor to ground

### HC-SR04 Ultrasonic Distance Sensor - Rear

Mirrors front sensor configuration at rear of chassis.

```
VCC  ──→ 5V regulated power
GND  ──→ Common GND
TRIG ──→ GPIO 15 (3.3V logic)
ECHO ──→ GPIO 35 (with voltage divider: 1kΩ series + 2kΩ to GND)
```

**Measurement Range:**
- Minimum: 2 cm
- Maximum: 400 cm
- Update rate: ~60 Hz
- Beam angle: ~15°

## Receiver & Communication

### FlySky FS-iA6B Remote Control Receiver (iBUS Protocol)

Receives wireless commands from remote transmitter using iBUS serial protocol.

```
VCC ──→ 5V regulated power
GND ──→ Common GND
Signal ──→ GPIO 23 (Serial2 RX, iBUS one-wire protocol)
```

**Communication Parameters:**
- Protocol: iBUS (Binary format)
- Baud rate: 115200
- Channels available: 14 (using 3 channels)
- Failsafe timeout: 500 ms

**Channel Mapping:**
- Channel 1: Steering input (1000-2000 μs range, 1500 center)
- Channel 2: Throttle/Speed (1000-2000 μs range, 1500 neutral)
- Channel 5: Autonomous mode toggle (< 1500 = manual, > 1500 = auto)

**Loss of Signal Handling:**
If no iBUS signal received for >500 ms:
- Motors stop immediately
- Servos center (90°)
- Autonomous mode disengages
- LED indicator (if present) blinks

### Raspberry Pi UART Connection

Serial link between ESP32 and Raspberry Pi for telemetry transmission and command reception.

```
ESP32 TX (GPIO 17)  ──→ RPi RX (GPIO 15 / UART0)
ESP32 RX (GPIO 16)  ──→ RPi TX (GPIO 14 / UART0)
GND (ESP32) ────────→ GND (RPi)
```

**UART Parameters:**
- Baud rate: 115200
- Data bits: 8
- Stop bits: 1
- Parity: None
- Handshaking: None

**Telemetry Packet Format:**
```
MODE:MANUAL
DIST_FRONT:123.5
DIST_REAR:95.2
LAT:26.123456
LON:82.654321
ROLL:1.2
PITCH:0.8
YAW:45.5
SATS:12
SIGNAL:98
END
```

Transmission rate: 10 Hz (every 100 ms)

## Complete GPIO Pinout

| GPIO | Function | Type | Voltage | Notes |
|---|---|---|---|---|
| 2 | HC-SR04 Front TRIG | Output | 3.3V | Digital pulse |
| 4 | Servo Front Left | PWM | 3.3V | 50 Hz, 1000-2000 μs |
| 5 | Servo Front Right | PWM | 3.3V | 50 Hz, 1000-2000 μs |
| 12 | BTS7960 #2 L_EN | Output | 3.3V | Always HIGH |
| 13 | BTS7960 #2 R_EN | Output | 3.3V | Always HIGH |
| 14 | BTS7960 #2 LPWM | PWM | 3.3V | 5 kHz reverse |
| 15 | HC-SR04 Rear TRIG | Output | 3.3V | Digital pulse |
| 16 | GPS RX (Serial1) | Input | 3.3V | UART receive |
| 17 | GPS TX (Serial1) | Output | 3.3V | UART transmit |
| 18 | Servo Rear Left | PWM | 3.3V | 50 Hz, 1000-2000 μs |
| 19 | Servo Rear Right | PWM | 3.3V | 50 Hz, 1000-2000 μs |
| 21 | MPU6050 SDA (I2C) | I/O | 3.3V | I2C data line |
| 22 | MPU6050 SCL (I2C) | I/O | 3.3V | I2C clock line |
| 23 | Receiver iBUS | Input | 3.3V | Serial2, 115200 baud |
| 25 | BTS7960 #1 RPWM | PWM | 3.3V | 5 kHz forward |
| 26 | BTS7960 #1 LPWM | PWM | 3.3V | 5 kHz reverse |
| 27 | BTS7960 #2 RPWM | PWM | 3.3V | 5 kHz forward |
| 32 | BTS7960 #1 L_EN | Output | 3.3V | Always HIGH |
| 33 | BTS7960 #1 R_EN | Output | 3.3V | Always HIGH |
| 34 | HC-SR04 Front ECHO | Input | 1.65V | With voltage divider |
| 35 | HC-SR04 Rear ECHO | Input | 1.65V | With voltage divider |

## Typical Current Draw

**During operation:**
- Motors (cruise): 5-8A per driver
- Motors (full load): 15-20A per driver
- Servos (idle): ~50 mA
- Servos (moving): 1-2A combined
- ESP32: 200-400 mA
- Raspberry Pi: 500 mA - 1.5A (depending on camera)
- Sensors: 100-200 mA

**Worst-case total:** 35-40A sustained (requires 5000+ mAh battery capacity)

## Assembly Best Practices

1. **Power Distribution:**
   - Use heavy gauge wire (10 AWG minimum) for main battery lines
   - Keep BTS7960 power cables short and direct
   - Add 10 μF electrolytic + 0.1 μF ceramic capacitors across driver power inputs

2. **Signal Integrity:**
   - Use shielded cables for long sensor runs
   - Keep signal wires away from high-current motor cables
   - Use twisted pairs for differential signals

3. **Grounding:**
   - Star-point ground connection at battery negative
   - Ensure all grounds are bonded together
   - Use separate signal and power grounds where possible

4. **Protection:**
   - 20A automotive fuse on main battery positive line
   - Diode across motor driver logic power for reverse polarity protection
   - Check for shorts with multimeter before first power-up

5. **Testing Steps:**
   - Verify all voltages before connecting ESP32
   - Test motor driver PWM independently first
   - Verify I2C sensors with I2C scanner
   - Test GPS UART with logic analyzer or serial monitor
   - Confirm servo center before attaching mechanisms

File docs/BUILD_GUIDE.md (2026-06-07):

# HexaRover Build Guide

## Introduction

This guide explains how to assemble the HexaRover platform using the provided CAD models, STL files, wiring diagrams, and firmware.

Before beginning, ensure that all required components have been manufactured or procured and that the repository files have been downloaded.

---

# Build Overview

The assembly process consists of five major stages:

1. Fabricate mechanical components
2. Assemble the chassis
3. Install the drive system
4. Wire the electronics
5. Upload firmware and test

Expected build time:

| Skill Level | Estimated Time |
| --- | --- |
| Beginner | 6–8 Hours |
| Intermediate | 3–5 Hours |
| Experienced Maker | 2–3 Hours |

---

# Required Tools

## Mechanical Tools

* Screwdriver set
* Needle nose pliers
* Side cutters
* Hex key set
* Measuring scale

## Electronics Tools

* Soldering iron
* Solder wire
* Wire stripper
* Multimeter

## Optional Tools

* Hot glue gun
* Heat shrink tubing
* Cable ties
* Thread locker

---

# Bill of Materials

## Electronics

| Component | Quantity |
| --- | --- |
| ESP32 Development Board | 1 |
| Motor Driver Module | 1 |
| DC Geared Motors | 2–6 |
| Battery Pack | 1 |
| Power Switch | 1 |
| Jumper Wires | As Required |

## Mechanical

| Component | Quantity |
| --- | --- |
| 3D Printed Parts | Refer CAD Files |
| Wheels | 2–6 |
| Fasteners | As Required |
| Chassis Panels | 1 Set |

---

# Step 1 — Print Components

Locate the STL files in:

```text
CAD/STL/
```

Print all required parts using the recommended settings.

## Recommended Print Settings

| Setting | Value |
| --- | --- |
| Material | PLA |
| Layer Height | 0.2 mm |
| Infill | 25% |
| Supports | Only Where Required |
| Wall Count | 3 |

## Verification Checklist

After printing:

* No visible cracks
* Mounting holes are clear
* Connectors fit together
* Parts match assembly drawings

---

# Step 2 — Assemble the Chassis

Using the assembly drawings provided in:

```text
CAD/Assembly/
```

construct the base frame.

## Procedure

1. Lay out all structural parts.
2. Assemble the primary frame.
3. Install reinforcement connectors.
4. Verify alignment.
5. Tighten all structural fasteners.

## Inspection

The chassis should:

* Sit flat on a surface.
* Have no major flexing.
* Maintain symmetrical dimensions.

---

# Step 3 — Install Motor Assemblies

Attach the motor mounts to the chassis.

Install each motor according to the assembly drawings.

## Procedure

1. Insert motors into mounts.
2. Secure using recommended fasteners.
3. Route motor wires inward.
4. Attach wheels.
5. Verify free wheel rotation.

## Verification

Each wheel should:

* Rotate freely.
* Have minimal wobble.
* Remain securely mounted.

---

# Step 4 — Mount Electronics

Locate the electronics mounting locations shown in:

```text
Hardware/Layout/
```

Install:

* ESP32
* Motor Driver
* Power System
* Sensor Modules (Optional)

## Recommended Placement

```text
Front
│
├── Sensors
│
├── ESP32
│
├── Motor Driver
│
└── Battery Pack
│
Rear
```

---

# Step 5 — Wiring

Follow the wiring diagrams located in:

```text
Hardware/Wiring/
```

## Wiring Sequence

### Power System

Connect:

Battery → Switch → Power Distribution

### Controller

Connect:

Power Distribution → ESP32

### Motor Driver

Connect:

Power Distribution → Motor Driver

### Motors

Connect:

Motor Driver → Drive Motors

---

# Step 6 — Firmware Installation

Navigate to:

```text
Firmware/
```

## Setup

1. Install Arduino IDE or PlatformIO.
2. Install ESP32 board package.
3. Open firmware project.
4. Select correct COM port.
5. Upload firmware.

## Verification

Successful upload should display:

```text
HexaRover Boot Complete
WiFi Initialized
Motor Controller Ready
System Ready
```

through the serial monitor.

---

# Step 7 — Initial Testing

Perform the following checks.

## Power Test

Verify:

* ESP32 powers correctly.
* No overheating.
* Stable voltage.

---

## Motor Test

Verify:

* Forward motion
* Reverse motion
* Left turn
* Right turn
* Emergency stop

---

## Communication Test

Verify:

* Bluetooth connection
  or
* Wi-Fi connection

---

# Troubleshooting

## Rover Does Not Power On

Check:

* Battery voltage
* Switch wiring
* Power connections

---

## Motors Do Not Move

Check:

* Driver wiring
* Motor polarity
* Firmware configuration

---

## ESP32 Not Detected

Check:

* USB cable
* Drivers
* COM port selection

---

## Rover Moves Incorrectly

Check:

* Motor orientation
* Wiring polarity
* Wheel installation

---

# Safety Notes

* Never short battery terminals.
* Disconnect power before wiring changes.
* Verify polarity before powering electronics.
* Keep wiring secured away from moving parts.
* Test on a stable surface before deployment.

---

# Build Completion Checklist

* [ ] All printed parts assembled
* [ ] Chassis secured
* [ ] Motors installed
* [ ] Electronics mounted
* [ ] Wiring completed
* [ ] Firmware uploaded
* [ ] Communication verified
* [ ] Motion verified
* [ ] Final inspection completed

---

# Next Steps

After successful assembly, users can:

* Add sensors
* Develop autonomous features
* Integrate cameras
* Build custom payloads
* Modify firmware
* Contribute improvements back to the project

Welcome to the HexaRover community and happy building!

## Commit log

2026-06-07 Update designs.md with new CAD images
    Added additional images to the CAD designs documentation.
2026-06-12 Add Raspberry Pi setup script for Python dependencies
2026-06-12 Add comprehensive hardware wiring documentation and pinout reference
2026-06-12 Add telemetry implementation for ESP32-to-Raspberry Pi UART communication
